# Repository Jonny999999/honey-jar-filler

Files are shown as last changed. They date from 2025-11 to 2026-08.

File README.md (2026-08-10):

# honey-jar-filler

Semi-automatic **weight-based honey jar filler** with a **jar carousel/magazine** and a
**servo-actuated honey gate**. A load cell weighs each jar in real time while the
firmware modulates the gate to hit a target fill mass.

This repository holds the complete build — **KiCad PCB**, **FreeCAD** mechanics, and
**ESP-IDF firmware** — plus the telemetry tooling used to capture and analyse fills.
The machine is also the subject of a **bachelor thesis** that evaluates several
**dosing strategies** for accurately dispensing a viscous, drifting medium (honey);
see [Dosing strategies](#dosing-strategies).

<p align="center">
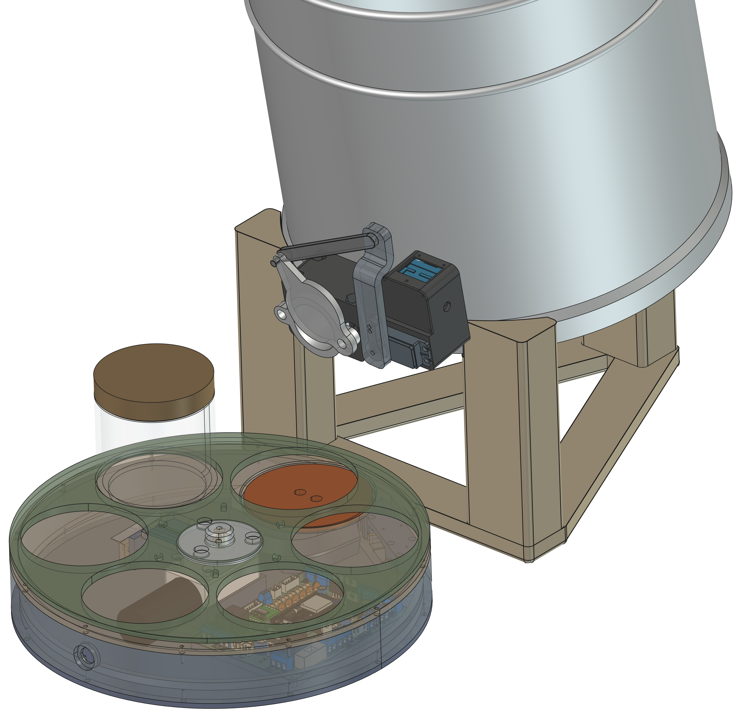
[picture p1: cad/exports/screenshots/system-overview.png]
System overview (CAD)
  
</p>

*System overview (CAD): pressurised bucket on the stand, the servo-actuated gate, and
the carousel base housing the control board and load cell, with a jar in position.*

<p align="center">
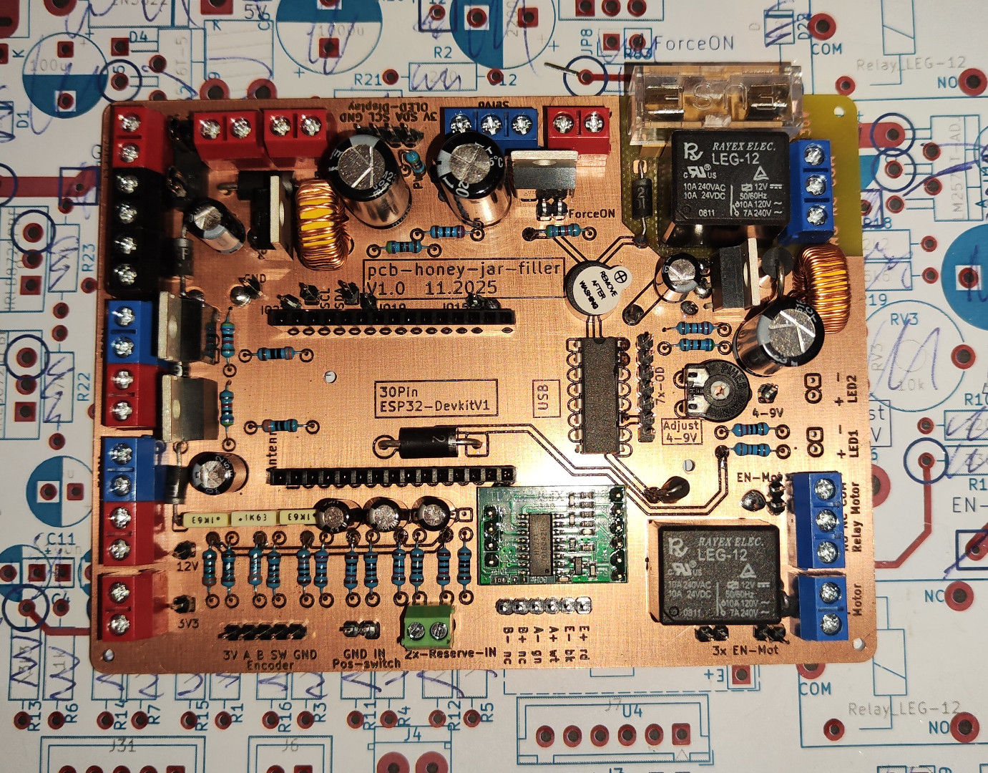
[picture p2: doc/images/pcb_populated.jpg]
Custom board fully populated
  
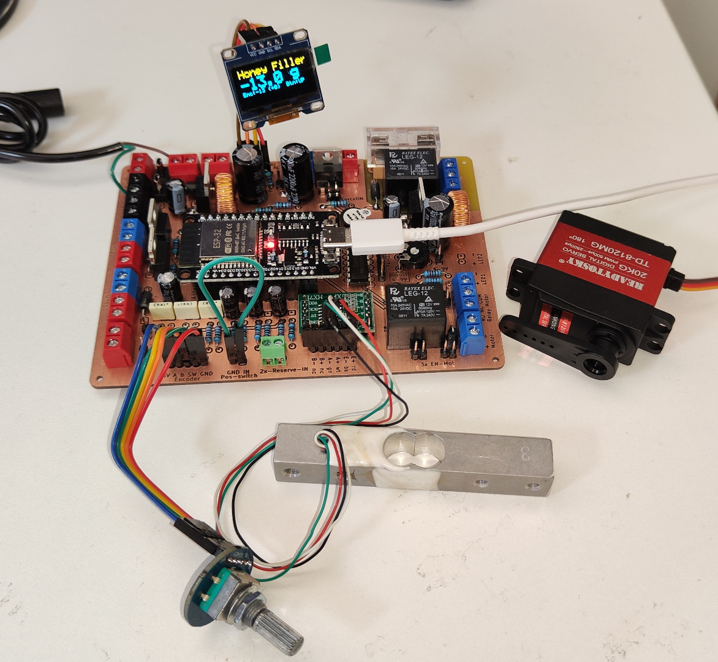
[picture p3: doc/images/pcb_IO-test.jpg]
I/O test with peripherals
  
</p>

*Left: the custom control board, fully populated. Right: I/O bring-up with all
peripherals connected.*

## Repo contents
- `pcb_honey-jar-filler/` — KiCad project (schematic, PCB, exports)
- `cad/` — FreeCAD parts, 3D models, full assembly
- `firmware_honey-jar-filler/` — ESP32 firmware (ESP-IDF)
- `tools/telemetry/` — host-side capture, run-splitting, and plotting tools
- `doc/` — build photos and notes

## Features (PCB / system)
- Load cell input (HX711) for weight-based dosing
- UI: rotary encoder, 2× buttons, LEDs, OLED display (I²C)
- Actuation: servo interface for honey gate; motor output for carousel
- Optional outputs: heater control, tank pressurization valve
- Power: 12–40 V input, 5 V buck (logic), adjustable 4–9 V rail (servo)

## Dosing strategies
Dosing honey accurately is hard: there is a **dead time** of several seconds between
moving the gate and seeing the weight respond, the flow **keeps dripping after the
gate closes**, the gate→flow relationship is **nonlinear**, and disturbances
(viscosity, temperature, falling bucket level) **drift within and between fills**.
Fixed thresholds therefore cannot stay optimal, which is what motivates the strategy
comparison at the heart of the thesis.

The firmware implements the strategies as interchangeable modules
(`firmware_honey-jar-filler/components/filler/`), selectable from the OLED menu:

- **heuristic** — fixed two-stage thresholds; the simple baseline.
- **adaptive-heuristic** — the same fill sequence, but dead time, post-close drip and
  fill rates are learned between fills, so it converges after a jar or two.
- **flow-cascade** — a control-based approach: an outer deceleration rate profile
  (feed-forward trajectory) feeding an inner PI rate loop with an online-identified
  affine plant model and Smith-predictor dead-time compensation.
- **manual** / **sequence** — encoder-driven and scripted modes, used for bring-up and
  for capturing clean reference runs.

## Roadmap / ideas
- Rotary carousel automation (indexing, run/stop with braking)
- Outlet warming (silicone band / water jacket)
- Jar presence detection
- Web UI / profiles / batch counter

## Schematic + layout preview
<p align="center">
  <a href="pcb_honey-jar-filler/export/pcb_honey-jar-filler.pdf">
    Schematic
  </a>
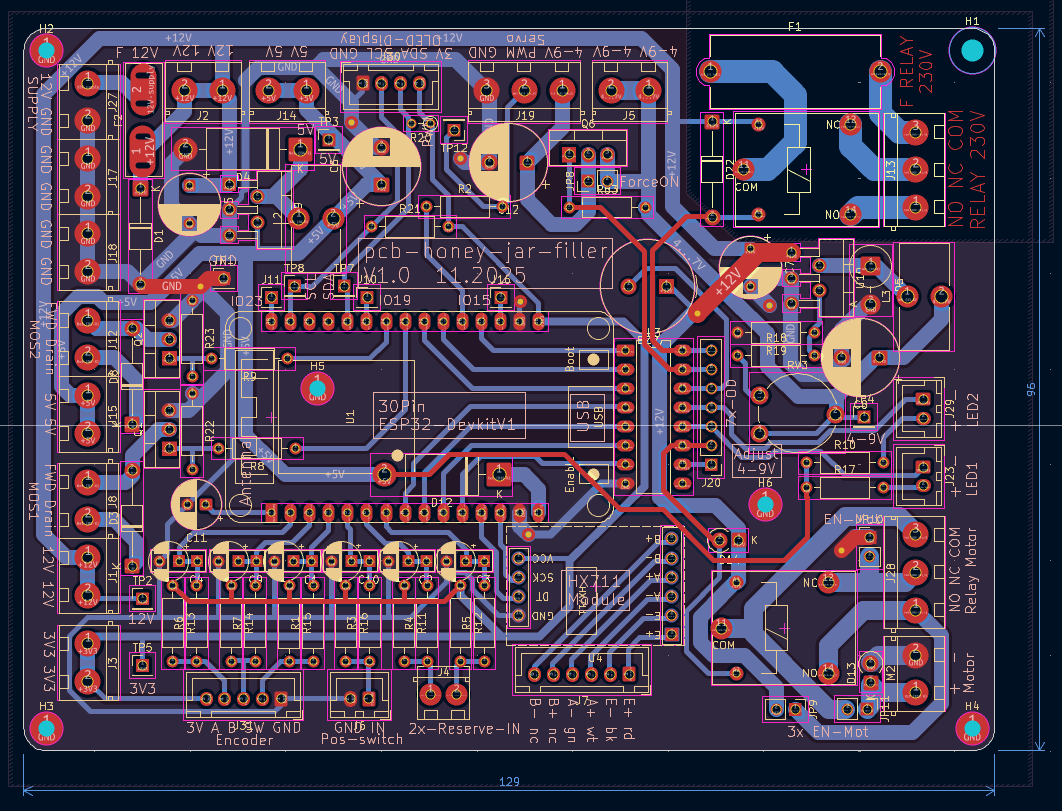
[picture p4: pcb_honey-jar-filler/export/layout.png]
PCB Layout
  
</p>

## Firmware build (ESP-IDF)
- Install ESP-IDF **v5.5.1** and export its environment (`. ./export.sh`).
- Enter the firmware project:
```bash
cd firmware_honey-jar-filler
```
- Set the target and build:
```bash
idf.py set-target esp32
idf.py build
```
- No separate "install components" step is needed — `idf.py build` auto-fetches
  the managed components listed in `main/idf_component.yml` (esp-idf-lib hx711/
  encoder, ssd1306, servo, led_strip) into `managed_components/` on first run.
  `managed_components/` and `build/` are gitignored and regenerated per machine.
- `dependencies.lock` **is** committed and pins exact component versions — do
  not delete it. Some `idf_component.yml` entries use unbounded ranges (e.g.
  `esp-idf-lib/hx711: '*'`), and upstream has shipped breaking API changes
  under those ranges before (`esp-idf-lib/encoder` v2.0.0 rewrote the whole
  API); without the lock file, a fresh clone can silently resolve to an
  incompatible version and fail to compile.
- Flash and monitor (adjust serial port as needed):
```bash
idf.py -p /dev/ttyUSB0 flash monitor
```

## Firmware presets
- Runtime parameters are still defined centrally in `firmware_honey-jar-filler/components/app/app_params_def.h`.
- Each parameter there has one baseline default plus metadata such as min/max/step, UI text, and a scope:
  `APP_PARAM_SCOPE_PRESET` for recipe-specific values and `APP_PARAM_SCOPE_MACHINE` for shared machine settings.
- Built-in preset names and their default overrides live in `firmware_honey-jar-filler/components/app/app.c`.
  These preset defaults only override recipe-scoped fields; they do not duplicate the full parameter list.
- NVS stores shared machine settings separately from editable preset values:
  `machine_v1` for shared settings and `presets_v1` for preset-specific values.
- At boot, the active runtime config is rebuilt from baseline defaults + selected preset defaults + persisted machine settings + persisted preset values.

## Telemetry tools
- Structured telemetry is emitted on the normal UART console with a `TEL ` prefix and JSON payload.
- Normal ESP logs and machine telemetry therefore share one serial stream, but the telemetry lines can be split cleanly on the host.
- The intended workflow is:
  1. capture a session from UART
  2. keep the full console log for debugging
  3. store telemetry separately as NDJSON
  4. split runs and generate thesis figures from those files

Current script layout:
- `tools/telemetry/telemetry_tui.py`
  Recommended interactive wrapper / TUI entrypoint. Guides the user through
  capture, split, and plotting with session discovery, defaults, and command
  previews, while still calling the underlying scripts directly.
- `tools/telemetry/src/`
  Internal shared helpers for the telemetry scripts. Not intended to be run
  directly.
- `tools/telemetry/capture.py`
  Fully usable serial capture tool. Replaces the basic `idf.py monitor` workflow for experiment sessions and shows a live status line with telemetry counters.
- `tools/telemetry/split_runs.py`
  Offline splitter that converts one captured session into per-fill NDJSON files.
  It detects jar filling windows from `state=FILL`, adds configurable pre/post context,
  and writes `fills/index.json` plus `fill_0001.ndjson`, `fill_0002.ndjson`, ...
- `tools/telemetry/plot_runs.py`
  Offline chart exporter for thesis figures. It writes both a plain LaTeX-ready
  chart and a debug variant with metadata, based on fill mass, gate percentage,
  and FSM state overlays.
- `tools/telemetry/strategy_compare.py`
  Cross-strategy comparison charts (accuracy point clouds, speed–accuracy
  trade-off, throughput) for the thesis' strategy-comparison chapter. Reads each
  session's per-fill summaries and is explicit about which runs are a controlled
  comparison and which are only indicative.
- `tools/telemetry/cascade_analyze.py`
  Diagnostics for the flow-cascade strategy: per-fill plant-model estimate
  (gain/onset/lag) beside an offline ground-truth fit, to spot a diverging
  identifier at a glance.

Session capture output:
- `data/telemetry/<session>/session.log`
  Full serial console output, including normal ESP logs and raw `TEL` lines.
- `data/telemetry/<session>/telemetry.ndjson`
  Only telemetry payload lines, one JSON object per line.
- `data/telemetry/<session>/runs/run_0001.ndjson`
  Per-run telemetry files created live from `run_start` / `run_end` events, including configurable pre/post context.
- `data/telemetry/<session>/fills/index.json`
  Offline manifest of detected jar-fill windows with timing, preset, and parameter metadata.
- `data/telemetry/<session>/fills/fill_0001.ndjson`
  One offline per-fill telemetry slice intended for plotting and later comparison.
- `data/telemetry/<session>/session_meta.json`
  Port, baud rate, and capture timing settings.

Example capture usage:
```bash
python3 tools/telemetry/capture.py --port /dev/ttyUSB0 --baud 115200
```

Recommended interactive workflow:
```bash
python3 tools/telemetry/telemetry_tui.py
```

Example offline workflow:
```bash
python3 tools/telemetry/split_runs.py data/telemetry/2026.06.12_11:39-x-test --force
python3 tools/telemetry/plot_runs.py data/telemetry/2026.06.12_11:39-x-test/fills --list
python3 tools/telemetry/plot_runs.py data/telemetry/2026.06.12_11:39-x-test/fills --fills 1,3 --format pdf --format svg
```

Useful options:
- `--show-tel`
  Also print the `TEL` lines in the terminal instead of only saving them to files.
- `--pre-run-ms 2000 --post-run-ms 2000`
  Keep more telemetry context around each detected run.
- `--session-name my-test`
  Add a readable suffix after the timestamp, for example
  `2026.06.07_22:30-x-my-test`.

Goal of this tooling:
- keep experiment data self-describing and reproducible
- avoid manually filtering UART logs after each test
- support later batch plotting to vector PDF/SVG figures for the thesis
- preserve enough event context to compare different presets and control strategies cleanly
- make it obvious during capture that the custom telemetry tool is running, not plain `idf.py monitor`

## Wiring (servo mount DIN cable)
The cable with 15-pin DIN connector from the base assembly to the servo mount carries OLED, encoder, and servo signals + power.

OLED:
- green: GND
- red: 3V3
- orange: SDA
- yellow: SCL

Encoder:
- gray: SW
- blue: B
- light-green: A

Servo:
- brown, gray-brown, pink: 8V
- gray-black, black, white: GND
- purple: PWM

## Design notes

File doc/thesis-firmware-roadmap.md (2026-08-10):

# Thesis Firmware Roadmap

## Purpose

This document captures the current firmware architecture and a practical roadmap for the next three major features:

1. Presets / parameter profiles
2. Web-based configuration and monitoring
3. Detailed process logging for later scientific comparison

The goal is to make future implementation work incremental and reproducible, without having to re-explain the project context.

## Current Firmware Snapshot

The firmware is already structured well enough to extend without a rewrite.

- `firmware_honey-jar-filler/components/app/app.c`
  Stores one versioned `app_params_t` blob in NVS and exposes `app_params_get()` / `app_params_set()`.
- `firmware_honey-jar-filler/components/app/app_params_def.h`
  Central source of truth for parameter defaults, limits, labels, units, descriptions, and grouping.
- `firmware_honey-jar-filler/components/app/app_params_meta.c`
  Builds a metadata table from the parameter definition macros.
- `firmware_honey-jar-filler/components/filler/filler_fsm.c`
  Owns the process state machine and pulls a fresh parameter snapshot every loop.
- `firmware_honey-jar-filler/components/ui/ui_task.c`
  Provides the runtime OLED status screen and direct encoder-based target editing.
- `firmware_honey-jar-filler/components/ui/ui_menu.c`
  Provides a metadata-driven settings menu with explicit save behavior.
- `firmware_honey-jar-filler/main/scale_hx711.c`
  Already has both a polling queue and a thread-safe "latest sample" snapshot.
- `firmware_honey-jar-filler/main/main.c`
  Initializes all peripherals and starts the FSM/UI tasks. There is no networking stack yet.

## Important Observations Before Adding Features

### 1. The current parameter model is centralized

This is a major advantage. Presets and a web UI do not need a second config model if they reuse `app_params_t` plus the existing metadata table.

### 2. Not all parameters should behave like honey presets

Some parameters are "recipe" values, others are "machine calibration" values.

Examples of likely recipe values:

- `target_grams`
- `target_tol_low_g`
- `target_tol_high_g`
- `slow_remaining_g`
- `slow_gate_pct`
- `max_gate_pct`
- `close_remaining_g`
- `drip_delay_ms`
- maybe `empty_glass_min_g` / `empty_glass_max_g` if jar type changes

Examples of machine-level values that should usually not change per honey preset:

- `gate_open_deg`
- `gate_close_deg`
- scale calibration data in `scale_hx711.c`
- maybe `slots_total`

Important detail:

- `gate_open_deg` and `gate_close_deg` are only applied during `gate_init()` in `main/main.c`.
- That means changing them through a preset or web UI will not fully apply live unless gate re-init is added.

Recommendation:

- Keep the first preset implementation simple, but treat calibration values carefully.
- Do not let daily recipe switching accidentally change hardware calibration.

### 3. Current NVS write behavior is fine for OLED use, but not ideal for a web UI

Today, some edits are explicit saves from the menu, but the encoder target adjustment writes to NVS on each change. A web UI with sliders or repeated edits would write far too often.

Recommendation:

- Introduce a RAM working copy plus explicit commit/save semantics before building the web editor.

### 4. The scale update rate is modest

Current default settings are:

- `CONFIG_HX711_POLL_INTERVAL_MS = 280`
- `CONFIG_HX711_AVG_SAMPLE_COUNT = 3`

That is acceptable for slow honey filling and threshold-based control, but may become limiting for more advanced algorithms based on trend or prediction.

Recommendation:

- Keep the current timing initially.
- Re-evaluate sampling rate only after logging exists and actual plots show whether the control signal is too coarse.

## Overall Evaluation

All three ideas are good and realistic.

### Presets

Very realistic and low risk. This is the best next step because it builds directly on the current parameter architecture and immediately helps experimentation.

### Web app

Realistic if kept lightweight. The ESP32 can host a small operator UI in AP mode, but the backend API and config semantics should be stabilized first. A minimal static app plus JSON API is a good fit.

### Logging

Essential for the thesis. This is not optional if the goal is scientific comparison. It is realistic, but it should be implemented as a dedicated telemetry/logging layer rather than scattered `ESP_LOGI()` calls.

## Recommended Order

1. Implement presets and improve parameter persistence semantics.
2. Implement a dedicated telemetry/logging backbone.
3. Add Wi-Fi AP + HTTP API.
4. Build the web UI on top of the API and telemetry stream.
5. Only then start comparing alternative control algorithms.

Why this order:

- Presets solve the immediate operational need.
- Logging should exist before algorithm experiments.
- The web app depends on stable preset/config and telemetry backends.

## Cross-Cutting Design Rule

Add new features through dedicated modules/tasks, not by spreading logic across UI and FSM code.

Recommended new modules:

- `components/presets/`
- `components/telemetry/`
- `components/web/`

The filler FSM should remain responsible for process control, not for storage, HTTP handling, or log transport.

## Task 1: Presets / Parameter Profiles

## Goal

Allow storing multiple named parameter sets and switching between them safely, for example:

- `Summer thin honey`
- `Cold thick honey`
- `500 g jar`
- `Archive 2026-04-22 trial B`

This is useful both operationally and scientifically.

## Why it is a good idea

- It removes the need to remember "good" values manually.
- It supports repeatable experiments.
- It creates a natural unit for later logging: every run can reference a preset name/id/revision.

## Refined decision: split preset settings from machine settings

Yes, the cleaner design is to exclude machine calibration and machine-specific operating limits from per-honey presets.

Recommended split:

- `Preset / recipe settings`
  Values that depend on honey, jar target, or fill strategy
- `Global / machine settings`
  Values that describe the specific hardware or installation

Recommended `global / machine settings` examples:

- `empty_glass_min_g`
- `empty_glass_max_g`
- `advance_timeout_ms`
- `find_ignore_ms`
- `slot_settle_ms`
- `slots_total`
- `gate_open_deg`
- `gate_close_deg`
- `scale_cal_ref_g`

Recommended `preset / recipe settings` examples:

- `target_grams`
- `target_tol_low_g`
- `target_tol_high_g`
- `fill_timeout_ms`
- `slow_remaining_g`
- `slow_gate_pct`
- `max_gate_pct`
- `close_remaining_g`
- `drip_delay_ms`

Why this split is better:

- changing honey should not accidentally change servo calibration
- the same machine can try many honey recipes safely
- logging becomes more meaningful because each run can reference both a `machine config revision` and a `recipe preset revision`
- the web UI becomes easier to understand because the user sees two clear categories

Recommended runtime model:

- keep one unified runtime `app_params_t`
- mark each field as either `PRESET` or `MACHINE`
- at boot, construct runtime params by merging:
  1. firmware base defaults
  2. selected built-in preset defaults
  3. persisted machine settings from NVS
  4. persisted user preset settings from NVS

This keeps the current control code simple because the FSM still reads one parameter struct.

## Recommended implementation

### Phase 1 design

Keep `app_params_t` as the active runtime parameter structure, but add:

- one machine-settings store
- one preset store
- a merge step into the active runtime struct

Suggested data model:

```c
typedef struct {
    char     name[24];
    uint32_t revision;
    int64_t  created_us;
    int64_t  updated_us;
    app_params_t params;
} app_preset_t;

typedef struct {
    uint16_t version;
    uint8_t  active_index;
    uint8_t  preset_count;
    app_preset_t presets[8];
} app_preset_store_t;
```

Suggested NVS layout:

- Namespace: `app`
- Key for machine settings: `machine_v1`
- Key for preset store: `presets_v1`
- Optional key for active working state later: `working_v1`

Suggested machine-settings model:

```c
typedef struct {
    uint16_t version;
    uint32_t revision;
    app_params_t params;
} app_machine_store_t;
```

Important detail:

- only the `MACHINE`-scoped fields inside `params` are meaningful for `machine_v1`
- only the `PRESET`-scoped fields inside `params` are meaningful for each preset

That means the same `app_params_t` and the same metadata can still be reused without duplicate struct definitions.

### Phase 1 API

Create a preset service instead of touching NVS directly from UI or web code.

Suggested API:

```c
void      app_presets_init(void);
esp_err_t app_presets_list(app_preset_t *out, size_t max_items, size_t *out_count);
esp_err_t app_presets_get_active(app_preset_t *out, uint8_t *out_index);
esp_err_t app_presets_select(uint8_t index, bool persist_now);
esp_err_t app_presets_save_active_to_slot(uint8_t index);
esp_err_t app_presets_create_from_active(const char *name, uint8_t *out_index);
esp_err_t app_presets_rename(uint8_t index, const char *name);
esp_err_t app_presets_delete(uint8_t index);
```

Suggested machine-settings API:

```c
void      app_machine_settings_init(void);
esp_err_t app_machine_settings_get(app_params_t *out_machine_only);
esp_err_t app_machine_settings_set(const app_params_t *in_machine_only);
```

### Parameter persistence change

Before presets or web editing, refactor `app_params` into:

- `app_params_get()` to read the current RAM copy
- `app_params_set_ram()` or equivalent public API for immediate runtime updates
- `app_params_commit()` to persist the active working copy to NVS

Reason:

- Web edits should not commit to flash on every input event.
- Preset editing should feel transactional: edit, test, save intentionally.

Recommended future semantics:

- runtime changes can happen immediately in RAM
- explicit save commits only the relevant scope:
  - save preset -> persist only `PRESET` fields into the active preset
  - save machine settings -> persist only `MACHINE` fields into `machine_v1`

### Safety rules

- Preset switching allowed only in `FILLER_IDLE` or `FILLER_FAULT`
- Never switch preset mid-fill
- Show the active preset name on OLED and later on the web UI
- Add a dirty flag when current RAM settings differ from the saved preset

### Migration path from the current firmware

On first boot with preset support:

1. Read the old single `app_params_t` blob if present.
2. Create a default preset from it, for example `Migrated default`.
3. Split the migrated values by scope:
   - `MACHINE` fields go to `machine_v1`
   - `PRESET` fields go to the new default preset
4. Mark that preset active.
5. Save the new store formats.

## OLED / menu behavior before the web app

The OLED should stay useful, but it should not become a full preset editor.

### Main screen

Recommended change:

- always show the active preset name on the normal runtime screen

Because the display is small, use one of these approaches:

- line 3 shows `Preset:<name>` and alternates every 1-2 s with `Btn:START Tgt:150g`
- or line 2 shows compact state info and line 3 always shows preset name

If the name is too long:

- store both a long name and a short label, or
- truncate to fit, for example 12-16 characters

This is worth doing early because it removes ambiguity during testing.

### Menu behavior

Recommended top-level menu flow before the web UI exists:

1. `Preset`
2. `Save to preset`
3. `Machine settings`
4. `Recipe settings`
5. existing actions like tare/calibrate

Minimal first OLED preset behavior:

- selecting `Preset` opens a list of existing presets
- rotating scrolls presets
- clicking applies the selected preset immediately
- application is only allowed in `IDLE` or `FAULT`
- after applying, all recipe-scoped runtime values update together
- machine-scoped values stay unchanged

Recommended save behavior:

- `Save to preset` writes the current recipe-scoped runtime values back to the active preset
- machine settings are not touched

This means the expected operator flow is:

1. choose preset first
2. all recipe values adjust together
3. optionally fine-tune a few recipe settings
4. save back to the active preset if the new tuning is good

That is the simplest usable pre-web workflow.

### Recommended UI scope for the first implementation

OLED support should stay minimal:

- Show active preset name
- Allow preset selection
- Allow "save current recipe to active preset"
- Keep advanced actions like rename/create/delete for the web UI

Do not try to build full preset management on the OLED first. That becomes tedious quickly. Advanced management belongs in the web UI.

### Calibration policy

Recommended policy for phase 1:

- Allow storing all values in the preset payload for simplicity
- But treat machine-calibration fields as advanced settings
- Document clearly that gate calibration may require restart to apply

Optional future refinement:

- Split settings into `machine_config` and `fill_recipe`
- Then presets contain only `fill_recipe`

With your current requirements, this is no longer just optional refinement. It is the recommended direction.

## Built-in preset defaults in the repo

You want named default presets to stay documented in the repo, while NVS overrides them at runtime if the user has saved values. That is a good idea.

Recommended approach:

### Keep one central parameter definition file

Continue using `app_params_def.h` as the single source of truth for:

- field list
- default baseline values
- type
- min/max/step
- labels and descriptions
- new field scope: `PRESET` or `MACHINE`

Do not duplicate full parameter structs per preset in code.

### Add built-in preset definitions as override tables

Recommended pattern:

1. Start from the normal firmware defaults
2. Apply only the preset-specific overrides

Conceptually:

```c
typedef struct {
    const char *name;
    void (*apply_overrides)(app_params_t *p);
} builtin_preset_def_t;
```

Example:

```c
static void preset_thick_honey(app_params_t *p)
{
    p->slow_remaining_g = 80;
    p->close_remaining_g = 180;
    p->drip_delay_ms = 14000;
}
```

Load flow:

1. call `app_params_apply_defaults()`
2. apply built-in preset overrides
3. apply persisted NVS values for that preset if present

Why this avoids chaos:

- adding a new parameter only requires updating the central macro file once
- existing built-in presets automatically inherit the new default unless they specifically override it
- no huge duplicate preset structs need maintenance

### Even cleaner future variant

If you want less handwritten override code later, add a tiny typed override table based on field metadata/offsets. Then a preset can be expressed as "only these fields differ". That keeps built-in presets compact even when many exist.

For the first implementation, simple override functions are sufficient and much easier to debug.

## Implementation steps

1. Add field-scope metadata: `PRESET` vs `MACHINE`.
2. Refactor `app_params` to support RAM-only update, explicit commit, and scope-based copy/merge helpers.
3. Add machine settings store (`machine_v1`).
4. Add preset store (`presets_v1`).
5. Add migration from the current single `params_v1` blob.
6. Add active preset tracking and preset selection API.
7. Expose active preset name/index to UI.
8. Add basic OLED preset selection and save flow.
9. Later expose the same API through HTTP.

## Acceptance criteria

- Multiple named presets can be created, selected, renamed, and deleted.
- Active preset survives reboot.
- Switching presets updates the runtime configuration without corrupting NVS.
- Preset switching is blocked while filling.
- Current preset information is visible locally.

## Risks / caveats

- NVS wear if edits still commit too often
- Confusion if calibration and recipe values are mixed without good naming
- Gate calibration values still being restart-sensitive

## Task 2: Web App for Configuration and Monitoring

## Goal

Provide an easier operator interface than the OLED/encoder for:

- monitoring state live
- viewing current weight and process state
- selecting or editing presets
- changing settings
- later seeing live plots and logs

## Why it is a good idea

- The OLED is good for local fallback, but not for managing many parameters and presets.
- A web UI naturally complements presets and logging.
- It can become the main thesis demo interface.

## Realism

This is realistic on ESP32 if the design stays small and deliberate.

Recommended scope:

- ESP32 in SoftAP mode
- lightweight static frontend
- JSON API for commands and configuration
- SSE for live monitoring stream

Avoid for the first version:

- heavy frontend frameworks unless already justified
- complex authentication systems
- trying to do full database-style storage on the ESP32

## Recommended backend architecture

### Network mode

Start with:

- ESP32 SoftAP mode
- fixed local IP, for example `192.168.4.1`
- WPA2 password configured in code or NVS

Later optional extension:

- AP+STA mode if you want laptop access through existing lab Wi-Fi

### HTTP server

Use ESP-IDF `esp_http_server`.

Recommended endpoints:

- `GET /api/status`
  Returns current machine snapshot
- `POST /api/control/start`
- `POST /api/control/abort`
- `GET /api/params/meta`
  Returns the existing parameter metadata table
- `GET /api/params/current`
- `PUT /api/params/current`
  Updates current working copy only
- `POST /api/params/commit`
  Explicit save
- `GET /api/presets`
- `POST /api/presets`
- `PUT /api/presets/{id}`
- `DELETE /api/presets/{id}`
- `POST /api/presets/{id}/activate`
- `GET /api/stream`
  Server-Sent Events for live data and events

### Why SSE is a good first choice

Use Server-Sent Events before WebSocket.

Reasons:

- simpler implementation
- good fit for one-way live telemetry
- browser support is straightforward
- commands can still use normal REST endpoints

WebSocket is only necessary if SSE becomes limiting later.

### Threading rule

HTTP handlers must not block the FSM or scale task.

Recommended pattern:

- read snapshots from dedicated service functions
- write control requests into queues/flags
- keep web task priority lower than scale/FSM tasks

## Recommended frontend architecture

The frontend should be intentionally small.

Recommended structure:

- single page
- plain HTML/CSS/JS or a very small build setup
- build once, serve static assets from flash

Suggested UI sections:

- machine overview
- current state, fault, slot, active preset
- large live weight readout
- preset selector and preset management
- parameter editor generated from metadata
- start/abort controls
- live plot area
- log export area

### Strong recommendation: metadata-driven parameter forms

Do not hardcode every setting twice.

Reuse:

- labels
- units
- min/max/step
- group names
- descriptions

from the existing parameter metadata. That keeps OLED, firmware, and web UI aligned.

## Suggested machine status payload

Expose a compact snapshot structure like:

```json
{
  "ts_us": 0,
  "state": "FILL",
  "fault": "NONE",
  "slot_index": 2,
  "slots_total": 6,
  "active_preset": "Cold thick honey",
  "weight_g": 132.4,
  "raw_weight": 123456,
  "jar_tare_g": 84.1,
  "relative_fill_g": 48.3,
  "gate_pct": 20,
  "motor_on": false,
  "params_dirty": false
}
```

This same snapshot can later feed the web monitor and telemetry logger.

## Implementation steps

1. Add Wi-Fi AP startup module.
2. Add HTTP server with a minimal `/api/status`.
3. Expose parameter metadata and current parameters.
4. Expose preset APIs.
5. Add SSE stream for status updates and events.
6. Add a minimal static frontend.
7. Add live plots after telemetry backend exists.

## Acceptance criteria

- A laptop/phone can connect directly to the ESP32 AP.
- The browser shows live machine status without serial monitor.
- Parameters can be edited and explicitly saved.
- Presets can be managed from the browser.
- Local OLED control still works as a fallback.

## Risks / caveats

- Flash/RAM limits if the frontend becomes too heavy
- Network handlers accidentally coupling too tightly to control logic
- Frequent browser edits causing too many flash writes if commit semantics are not fixed first

## Task 3: Detailed Logging for Scientific Comparison

## Goal

Create a reliable and clean logging system for later thesis analysis, including:

- time series of process values
- state transitions
- faults
- preset and parameter context
- per-run summaries

## Why it is a good idea

This is the most important thesis-oriented feature because it turns "it feels better" into measurable evidence.

Without structured logs, comparing parameter sets or control strategies will be weak.

## Core recommendation

Do not rely on scattered `ESP_LOGI()` output as the scientific log.

Instead, create a dedicated telemetry/logging module with a stable record format and separate output transports.

## Recommended architecture

### Logging layers

1. Producers
   The scale task, filler FSM, UI, preset service, and later web/API layer produce telemetry records.
2. Telemetry queue
   A single queue receives structured records.
3. Telemetry task
   One task timestamps, enriches, buffers, and forwards records.
4. Transports
   UART, Wi-Fi SSE, and optional on-device ring buffer use the same record source.

### Record types

Suggested record classes:

- `RUN_START`
- `RUN_END`
- `STATE_CHANGE`
- `FAULT`
- `SAMPLE`
- `GATE_COMMAND`
- `PARAM_CHANGE`
- `PRESET_CHANGE`
- `USER_ACTION`
- `NOTE`

### Suggested telemetry record

```c
typedef enum {
    TEL_RUN_START,
    TEL_RUN_END,
    TEL_STATE_CHANGE,
    TEL_FAULT,
    TEL_SAMPLE,
    TEL_GATE_COMMAND,
    TEL_PARAM_CHANGE,
    TEL_PRESET_CHANGE,
    TEL_USER_ACTION,
} telemetry_kind_t;

typedef struct {
    int64_t ts_us;
    uint32_t run_id;
    telemetry_kind_t kind;
    filler_state_t state;
    filler_fault_t fault;
    uint8_t slot_idx;
    float weight_g;
    float jar_tare_g;
    float relative_fill_g;
    float gate_pct;
    uint32_t target_g;
    char preset_name[24];
    uint32_t preset_revision;
    uint16_t algorithm_id;
    uint16_t algorithm_revision;
} telemetry_record_t;
```

The exact struct can change, but the design should include:

- timestamp
- run id
- preset identity
- algorithm identity
- main process values

## What should be logged

### Per-sample time series

At each published sample, capture at least:

- timestamp
- raw scale value
- calibrated weight
- relative fill weight
- FSM state
- slot index
- gate command percent
- target grams
- active preset id/name
- run id

### Events

Log immediately:

- start requested
- abort requested
- state changes
- near-close transition
- close-early transition
- refill decision
- overweight fault
- motor timeout
- scale stale fault
- preset switched
- parameters committed

### Per-run summary

At the end of each jar or run, produce a summary containing:

- run id
- preset id/name/revision
- algorithm id/revision
- start/end timestamps
- initial jar tare
- final net fill weight
- absolute error from target
- refill count
- time spent filling
- time spent dripping
- final result: ok / skipped / fault

This summary is extremely useful for thesis tables even without plotting the full time series.

## Transport recommendation: separate data model from transport

### UART

Best for first implementation.

Advantages:

- simple
- reliable
- easy to capture on a laptop
- good for debugging before Wi-Fi exists

Recommended output format:

- NDJSON or CSV lines

NDJSON is especially attractive because the same record format can later be reused over HTTP/SSE.

### Wi-Fi

Best for integration with the web UI once the API exists.

Recommended use:

- live telemetry stream to browser
- optional host-side logger tool over HTTP/SSE

### On-device persistence

Do not try to persist high-rate full time series in NVS.

Reasons:

- too much flash wear
- too little capacity
- unnecessary complexity

Recommended instead:

- keep a RAM ring buffer for recent records
- optionally persist only per-run summaries
- store full data on a connected host via UART or Wi-Fi

## Recommended first implementation strategy

### Phase 1

Add telemetry module and UART export only.

This is enough to:

- collect real experiment data
- inspect plots on a laptop
- validate the record format

### Phase 2

Expose the same telemetry stream via Wi-Fi SSE and show it in the web app.

### Phase 3

Add host-side tooling in the repo, for example:

- `tools/log_capture.py`
- `tools/plot_run.py`
- `tools/notebooks/`

The thesis analysis will almost certainly be easier in Python/pandas/matplotlib than inside the ESP32 itself.

## Clean integration points in the current code

Recommended producers:

- `main/scale_hx711.c`
  Publish `SAMPLE`
- `components/filler/filler_fsm.c`
  Publish state transitions, faults, run start/end, gate decisions
- `components/app/` or future preset service
  Publish param commit and preset change events
- `components/ui/ui_task.c`
  Publish user actions like start/abort or target edits if useful

## Acceptance criteria

- Each experimental run has a unique run id.
- Logs can be captured on a laptop without modifying the control loop.
- Logs include preset identity and enough state to reconstruct the fill process.
- Per-run summaries can be exported for thesis tables.
- Live monitoring later reuses the same telemetry source.

## Risks / caveats

- Logging too much directly from high-priority tasks
- Mixing debug logs with scientific logs
- Depending only on browser-side capture for important data

## Recommendation on Algorithm Experiments

Do not start with multiple new control algorithms before presets and logging exist.

First make experiments repeatable and measurable.

After that, the firmware should expose an explicit algorithm identity, for example:

- `ALGO_THRESHOLD_V1`
- `ALGO_THRESHOLD_V2`
- `ALGO_PREDICTIVE_CLOSE_V1`

Recommended future refactor:

- keep the FSM states
- isolate the fill decision logic behind a controller function or small strategy interface

This will make comparisons much cleaner in the thesis because only the control strategy changes while the surrounding machine logic stays constant.

## Final Recommendation

The three ideas are worthwhile, but they should not be started in parallel.

Best next action:

1. Presets plus better config persistence semantics
2. Structured telemetry/logging
3. Wi-Fi API
4. Web UI

If only one feature is implemented next, it should be presets.

If the goal is specifically thesis quality, the second feature after presets should be logging, not the web UI.

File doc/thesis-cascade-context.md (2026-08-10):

# Thesis context brief — regelungsbasierter Ansatz (flow-cascade)

**Purpose.** Self-contained context for a separate Claude session that writes the
LaTeX thesis section on the cascade / control-based dosing strategy. It captures
the *design rationale, rejected alternatives, and limitations* that are NOT
recoverable from reading the code alone, plus pointers to the code and the
telemetry data to interpret. Read this together with the code and the charts;
this file is the "why", the code is the "what", the telemetry is the "results".

> **Do not paste code verbatim into the thesis.** Use this to reason about and
> justify the design in prose/equations in Jonny's established chapter style.

---

## 0. Target file / chapter — CONFIRM FIRST

Jonny pointed at `09_erweiterte_dosierstrategie.tex`, but the chapter naming says
otherwise. Current chapters in `/home/jonny/HAW-LA/s8/latex/Chapters/`:
- `08_heuristische_dosierstrategie.tex` — heuristic (baseline).
- `09_erweiterte_dosierstrategie.tex` — **adaptive-heuristic** (the "erweiterte"
  learning strategy). The cascade is NOT this one.
- `10_regelungsbasierter_ansatz.tex` — **the cascade / control-based approach.
  This is the section this brief is for.**
- `11_strategievergleich.tex` — comparison.

→ The cascade material almost certainly belongs in **`10_regelungsbasierter_ansatz.tex`**.
Confirm with Jonny before writing into `09`. (09 and 10 share the same learning
substrate, so some cross-referencing between them is expected.)

---

## 1. Absolute paths

**Firmware — the cascade strategy and its shared substrate**
- Cascade implementation (primary):
  `/home/jonny/projects/honey-jar-filler/firmware_honey-jar-filler/components/filler/filler_strategy_flow_cascade.c`
- Runtime/learned-entry structs, telemetry field defs:
  `/home/jonny/projects/honey-jar-filler/firmware_honey-jar-filler/components/filler/filler_strategy.h`
- Adaptive strategy (shared learning model, ch.09, useful for contrast):
  `/home/jonny/projects/honey-jar-filler/firmware_honey-jar-filler/components/filler/filler_strategy_adaptive_heuristic.c`
- Flow-control strategy (single P-loop, the conceptual step *before* the cascade):
  `/home/jonny/projects/honey-jar-filler/firmware_honey-jar-filler/components/filler/filler_strategy_flow_control.c`
- Sequence strategy (scripted plant probe, produces the clean Strecke reference):
  `/home/jonny/projects/honey-jar-filler/firmware_honey-jar-filler/components/filler/filler_strategy_sequence.c`
- Preset params (targets/seeds/bounds): 
  `/home/jonny/projects/honey-jar-filler/firmware_honey-jar-filler/components/app/app_params_def.h`

**Supporting docs**
- Handoff/orientation (project-wide context): `/home/jonny/projects/honey-jar-filler/CLAUDE.md`
- Hardware retest checklist for the cascade fixes:
  `/home/jonny/projects/honey-jar-filler/doc/cascade-affine-gain-testnotes.md`

**Telemetry data — 2026-07-05 hardware session** (dir:
`/home/jonny/projects/honey-jar-filler/data/telemetry/`). Each run dir has
`telemetry.ndjson` (per-sample) + a per-fill summary; plot with
`tools/telemetry/plot_runs.py`.
- `2026.07.05_21:00-x-dunkler-honig_cascade_ratereduced-learnfromoverfill/` —
  **THE cascade run to discuss.** Real dark honey. Shows the three problems the
  fixes address (overfill +15..23 g every fill, gate stays ~full open until
  close, model K drifts 0.59→0.29). This is "cascade, pre-fix" data.
- `2026.07.05_19:55…_cascade-default01/`, `…20:07…cascade-02-fix-more-flow/`,
  `…20:21…cascade-03-allow100percent/`, `…20:24…cascade-04-retry/` — earlier
  same-day cascade runs on **dummy honey** (tuning iterations; lower value,
  context only).
- `2026.07.05_21:09-x-dunkler-honig_sequence_30-70longer/` — **scripted Strecke
  probe** (sequence strategy, gate 30 %→70 %→close). Best data for showing the
  raw plant response in isolation: dead time, rate build-up per gate step,
  post-close drip. Use for the Strecke/Prozessanalyse figure this section leans on.
- `2026.07.05_21:10-x-dunkler-honig-manual-sweep/` — **manual gate sweep**.
  Directly evidences the gate→flow relationship (nonlinearity + non-zero flow
  onset). Strong empirical support for the affine-model justification below.
- `2026.07.05_20:41…adaptive_default-quick-learn/`,
  `…20:45…adaptive_slow-learning/` — adaptive strategy (ch.09 learning trend).
- `2026.07.05_21:13…flowcontrol_rest/` — flow-control strategy.

> Caveat: all cascade fills in these runs are **pre-fix**. The affine-model +
> overfill + profile fixes (commit `63dc0d6`) are **untested on hardware**. Write
> the results section around the pre-fix data as "erste Inbetriebnahme / erkannte
> Probleme", and frame the fixes as the corrective design step — do NOT claim
> post-fix performance numbers until a retest exists.

---

## 2. What the cascade strategy is (architecture)

The "regelungsbasierter Ansatz": a **cascade control** with feedforward and
dead-time compensation, closing the loop on the **mass flow rate** ṁ rather than
on weight thresholds. Actuator is the gate/flap position α ∈ [0,100] %; the
controlled variable inside the loop is ṁ [g/s]; the outer objective is hitting
the target mass.

Layers, outer → inner:

1. **Outer trajectory / deceleration profile** (`profile_target_rate_gps`,
   flow_cascade.c ~L547). A *function of the remaining mass*, NOT a feedback
   loop. Produces the rate setpoint ṁ*(remaining):
   - `terminal = clamp(fast · 0.25, 3 g/s, fast)` — a genuine slow approach rate.
   - `in_flight = L̂·ṁ_meas + post_close_gain` — mass that will still arrive after
     "now" (dead-time + drip), subtracted so the taper is referenced to the
     mass that is *still controllable*: `eff_remaining = remaining − in_flight`.
   - `band = max(20 g, post_close·1.6 + L̂·fast)` — the deceleration window width,
     scaled by the plant's own lag/drip.
   - `frac = clamp(eff_remaining / band, 0, 1)`;  **ṁ\* = terminal + (fast − terminal)·frac**.
   → a linear taper from the fast cruise rate down to the terminal approach rate
   as the jar fills.

2. **Inner PI rate loop with feedforward** (`cascade_control_step`, ~L590):
   - Feedforward (Steuerung baseline): **gate_ff = (ṁ* − b) / K̂** — invert the
     learned affine plant model to get the gate that should produce ṁ*.
   - PI trims the residual: `gate = gate_ff + Kp·e + I`, with `Kp = 1.2 %/(g/s)`,
     integral gain `Ki = 0.40 %/(g/s·s)`, anti-windup clamp `I ∈ ±35 %`,
     per-update slew clamp `±6 %`, deadband `0.6 g/s`.
   - **Dead-time-paced holdoff**: the integrator is advanced by a holdoff time
     tied to the dead time (300–2500 ms), so the loop does not react faster than
     the plant can physically respond — a pragmatic dead-time defense.

3. **Smith predictor** (`cascade_update_model`, ~L389) forms the feedback the PI
   error uses: **e = ṁ* − fb**, where **fb = ŷ + (ṁ_meas − ŷ_d)**.
   - ŷ = model rate: the affine steady-state rate `K̂·gate + b` passed through a
     first-order lag `τ = 0.60 s` (`CASC_MODEL_TAU_S`).
   - ŷ_d = ŷ delayed by the learned dead time L̂ (a 256-deep ring buffer).
   - Cold-start: while history < L̂, ŷ_d = 0, which prevents predictor windup
     during the initial dead time when measured rate is also ~0.
   → Standard Smith structure: the controller "sees" the fast model prediction ŷ
   for responsiveness, corrected by the slow real measurement mismatch
   (ṁ_meas − ŷ_d) for accuracy.

4. **Online plant identification** — the affine model `K̂, b` (section 3).

**Shared FSM & learning substrate** (common with adaptive/flow-control):
`FILLER_FILL → DRIP_WAIT → VERIFY_TARGET → (refill loop)`. Per-preset learned
entries via count-warmup EWMA (`learn_ewma`, `α = max(base, 1/(n+1))`) so the
first successful fill dominates the conservative seed → converges in ~1–2 jars.
Learned per preset: dead_time, post_close_gain, fast/slow rate, drip_wait,
finish_trim, and `K̂,b`. **Learned state is RAM-only** (no NVS) — a reboot resets
to seeds; this is intentional so cold-start convergence is demonstrable.

---

## 3. The central design decision: the plant model  ṁ = K̂·gate + b

This is the most defensible/interesting design story for the thesis, because two
alternatives were tried and rejected first.

**The plant:** gate→flow is nonlinear, has a **non-zero flow onset** (~15 % gate
before any honey moves — see the manual-sweep run), and drifts with viscosity /
temperature / falling bucket level. So no fixed gate↔rate map holds.

**Attempt 1 — single scalar gain K̂ (`ṁ = K̂·gate`, line through origin).**
Failed because forcing the line through the origin makes `K̂ = ṁ/gate`
operating-point-dependent: near onset it's small, wide open it's larger. Sampling
K̂ at 60 % gate then using it at 30 % mis-predicts. In the 07-05 cascade run this
showed as an *apparent* K drift 0.59→0.29 — not the plant changing, but the
scalar being read off a curve at different points.

**Attempt 2 — 6-point gate→rate breakpoint schedule (10/20/…/90 %), interpolated.**
Rejected on a structural argument (this is the key insight): **the cascade
controller only ever visits two gate regimes** — a high gate during the fast
cruise phase and a low gate during the terminal approach. It never parks at the
intermediate breakpoints long enough (past the dead time) to gather steady-state
data there, so those points stay at their seed values forever and the
interpolation is fiction. A model the controller cannot excite is untrainable.

**Chosen — affine model `ṁ = K̂·gate + b`.** One slope + one offset:
- `b` (offset, clamped [−60, +15] g/s, **normally negative**) captures the flow
  onset the origin-line missed. Interpretation: gate at which flow starts ≈ −b/K̂.
- Fit **live from exactly the two operating points the controller does visit**:
  the fast phase feeds a high-gate EWMA point (gate_hi, rate_hi), the slow phase
  a low-gate point (gate_lo, rate_lo). Refit each update: `K̂ = Δrate/Δgate`,
  `b = rate_hi − K̂·gate_hi`, but only when the two gates are ≥ 8 %
  (`CASC_GAIN_MIN_GATE_SEP_PCT`) apart (else hold K̂, re-solve only b).
- Samples are taken **only in steady state** — gate held longer than
  `L̂ + 0.5 s` — so a measured rate reflects the *current* gate, not the one
  commanded a dead time ago. In-fill EWMA `α = 0.15`; the converged K̂,b persist
  across fills via signed-safe `learn_ewma`.
- **First-fill caveat:** `b` seeds to 0, so the very first fill's feedforward runs
  slightly rich at low gates until `b` is learned. Converges within a fill or two.

Framing for the thesis: this is a **linearized (affine) secant model** valid
*between* the two operating points, identified online — deliberately the simplest
model that (a) the controller can actually excite and (b) captures the onset
offset. Honest about being a local approximation of a nonlinear Strecke.

---

## 4. Steuerung vs. Regelung — the terminology framing

Useful for precise German control-engineering language:
- The **outer deceleration profile is a Steuerung / Trajektoriengenerator**: ṁ*
  is a pure function of remaining mass, no feedback. It is *not* a control loop.
- The **inner PI + feedforward is the Regelung**: feedback closes on the rate
  error via the Smith-predicted rate.
- The **feedforward term (gate_ff = (ṁ*−b)/K̂) is a modellbasierte Vorsteuerung**
  inside the Regelung — it does the bulk of the work; the PI only trims.
- The overall structure = **Kaskadenregelung mit Smith-Prädiktor und Vorsteuerung**.
Calling the whole strategy "regelungsbasierter Ansatz" is correct; be precise
that the outer layer itself is a Steuerung.

---

## 5. Why a smooth taper instead of a hard step (design justification)

For a plant with **dead time + drip (Nachlauf)**, arriving at the close point
*slowly* is what makes the close precise. Reasons to develop in prose:
- **Dead time:** a command arrives ~L̂ later. A hard step down still has the old
  high flow in flight during L̂ → overshoot. A ramp bleeds the rate down *before*
  the close, so the in-flight mass in the final L̂ is already small.
- **Drip ∝ rate-at-close:** post-close gain scales with the flow when the gate
  shuts. Arriving at ~terminal (≈0.25·fast) instead of full rate makes the drip
  small *and predictable*, which is what the post-close-gain learning relies on.
- **Loop health:** a hard step slams the PI with a huge transient and excites
  windup; the ramp keeps the error small and the loop in its linear regime.
- The optimum is "arrive as slowly as precision needs, but no slower" (slower =
  wasted cycle time). Linear taper = simplest monotonic profile with an
  independently tunable terminal rate. A `sqrt`/constant-deceleration profile
  would be marginally more time-optimal — note as *Ausblick/future work*, not done.

---

## 6. Deliberately NOT implemented (limitations / future work — be honest)

Good thesis material; frame as documented limitations, several absorbed to first
order by other mechanisms:
- **Within-fill dead-time variation not compensated.** L̂ is measured once at fill
  start and held constant, but L actually *shrinks* as the jar fills (fall height
  drops). The `finish_trim` cross-run integrator + the Smith correction absorb the
  resulting bias to first order, but it is not explicitly modeled.
- **K̂ is a single linearized/affine secant**, sampled only in steady state.
  Gate→flow is genuinely nonlinear; extrapolating K̂,b outside the two operating
  points is unreliable.
- **No NVS persistence** of learned state — reset on reboot (intentional for the
  cold-start demonstration, but a product would persist it).
- **Terminal rate is a fixed fraction (0.25) of fast**, not itself optimized.
- **Two-point ID needs a distinct slow phase** (≥ 8 % gate separation). If a fill
  never really slows, only `b` updates and K̂ is held — a structural dependency
  worth stating.
- **Untested post-fix on hardware** — the affine model and the overfill/profile
  fixes are validated only in reasoning/replay, not yet on the machine.

---

## 7. The empirical story (interpreting the 07-05 cascade run)

The `…21:00…cascade_ratereduced-learnfromoverfill` run is the honest "erste
Inbetriebnahme" evidence. Three coupled failure modes, all with a root cause:
1. **Overfill +15..23 g every fill.** Root cause: the close-threshold clamp
   collapsed to 10 g while the predicted remaining-at-close was 70+ g, so the
   gate closed far too late. (Also a double-count: post_close_gain already
   includes the in-flight mass, and the old code added dead_time·rate on top.)
2. **Gate stayed ~fully open until the very end** (no visible deceleration).
   Root cause: fast_rate and slow_rate had both collapsed to ~30 g/s, so the
   taper referenced to the learned slow rate was flat.
3. **Model prediction drifted worse across fills** — the scalar-K artifact of
   section 3 (K read off a nonlinear curve at a shifting operating point).

The corrective design step (commit `63dc0d6`): affine model (fixes 3), decouple
terminal rate from the learned slow rate as `0.25·fast` (fixes 2), and fix the
close-threshold clamp + remove the double-count (fixes 1). Present the fixes as
*design iterations driven by the measured Strecke behaviour* — a strong narrative
for a "regelungsbasierter Ansatz" chapter.

Supporting figures worth generating: the **manual-sweep** run for the gate→flow
nonlinearity + onset (justifies the affine model empirically); the **sequence**
run for the isolated Strecke response (dead time, per-step rate build-up, drip);
the cascade run for the failure modes above.

---

## 8. Key constants (values, for the equations/tables)

From `filler_strategy_flow_cascade.c`. Cite as tuned #defines, not learned.

| Constant | Value | Meaning |
|---|---|---|
| `CASC_KP_PCT_PER_GPS` | 1.2 | PI proportional gain [%/(g/s)] |
| `CASC_KI_PCT_PER_GPS_S` | 0.40 | PI integral gain [%/(g/s·s)] |
| `CASC_STEP_MAX_PCT` | 6.0 | max gate change per update [%] |
| `CASC_INTEG_LIMIT_PCT` | ±35 | anti-windup integrator clamp [%] |
| `CASC_DEADBAND_GPS` | 0.6 | rate-error deadband [g/s] |
| `CASC_HOLDOFF_MIN/MAX_MS` | 300 / 2500 | dead-time-paced integrator holdoff [ms] |
| `CASC_TERMINAL_RATE_FRAC` | 0.25 | terminal rate = frac·fast |
| `CASC_RATE_MIN_FLOOR_GPS` | 3.0 | terminal-rate floor [g/s] |
| `CASC_DECEL_BAND_MIN_G` | 20 | min deceleration window [g] |
| `CASC_DECEL_BAND_MULT` | 1.6 | post_close multiplier in band width |
| `CASC_GATE_GAIN_MIN/MAX` | 0.02 / 3.00 | affine slope K̂ bounds [g/s per %] |
| `CASC_GAIN_B_MIN/MAX` | −60 / +15 | affine offset b bounds [g/s] |
| `CASC_GAIN_MIN_GATE_SEP_PCT` | 8 | min gate separation to refit slope [%] |
| `CASC_GAIN_SETTLE_MARGIN_S` | 0.5 | settle margin over L̂ before sampling [s] |
| `CASC_GAIN_LIVE_ALPHA` | 0.15 | in-fill operating-point EWMA α |
| `CASC_MODEL_TAU_S` | 0.60 | Smith model first-order lag τ [s] |
| `SMITH_DELAY_MAX` | 256 | Smith delay ring-buffer depth |

Telemetry fields to reference in result plots (per-sample NDJSON): `weight`,
`gate`, `filtered_rate`, `target_rate_gps` (ṁ*), `rate_error_gps`,
`model_rate_gps` (ŷ), `model_delayed_gps` (ŷ_d), `control_integ_pct` (PI state),
`gate_gain_gps_per_pct` (K̂). Per-fill summary has `used_*`/`next_*` for
learning-trend plots.

---

## 9. Suggested section structure (10_regelungsbasierter_ansatz.tex)

1. Motivation: why thresholds/heuristics can't stay optimal on a drifting,
   dead-time+drip plant → close the loop on rate (link back to ch.07 Strecke).
2. Regelungskonzept: the cascade (Steuerung profile → PI+Vorsteuerung → Smith),
   with the block diagram (drawio `diagrams_flow-cascade_DRAFT.drawio`).
3. Streckenmodell: the affine ṁ = K̂·gate + b, the online two-point ID, and the
   rejected-alternatives argument (scalar / breakpoints) — the design highlight.
4. Trajektorie/Steuerung: the deceleration profile + why smooth vs. hard step.
5. Totzeitkompensation: the Smith predictor.
6. Inbetriebnahme & erkannte Probleme: the 07-05 results + corrective iteration.
7. Grenzen & Ausblick: section 6 limitations.

Keep consistent with ch.08/09 style (pastel figures, `#555555` borders,
Helvetica 13 in diagrams). Cross-reference the shared learning model in ch.09
rather than repeating it.

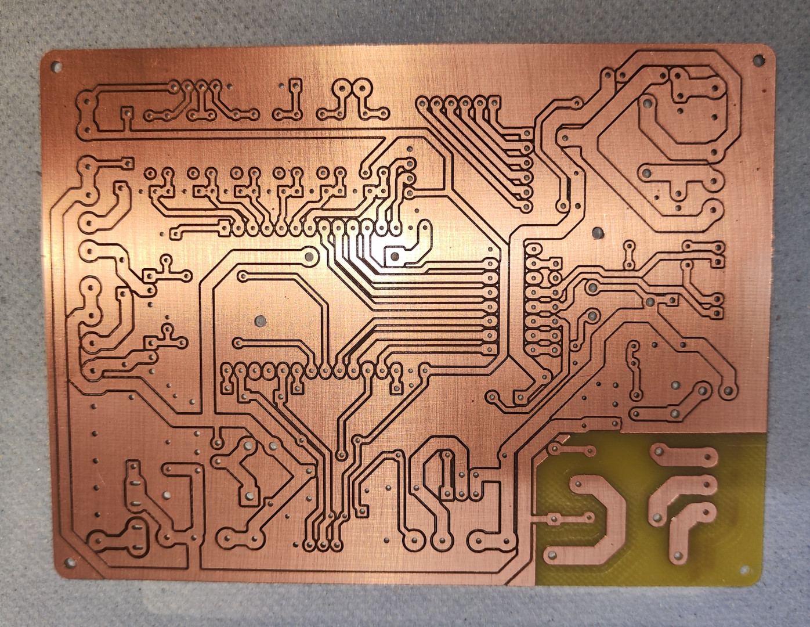
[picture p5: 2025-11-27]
doc/images/pcb_milled.jpg

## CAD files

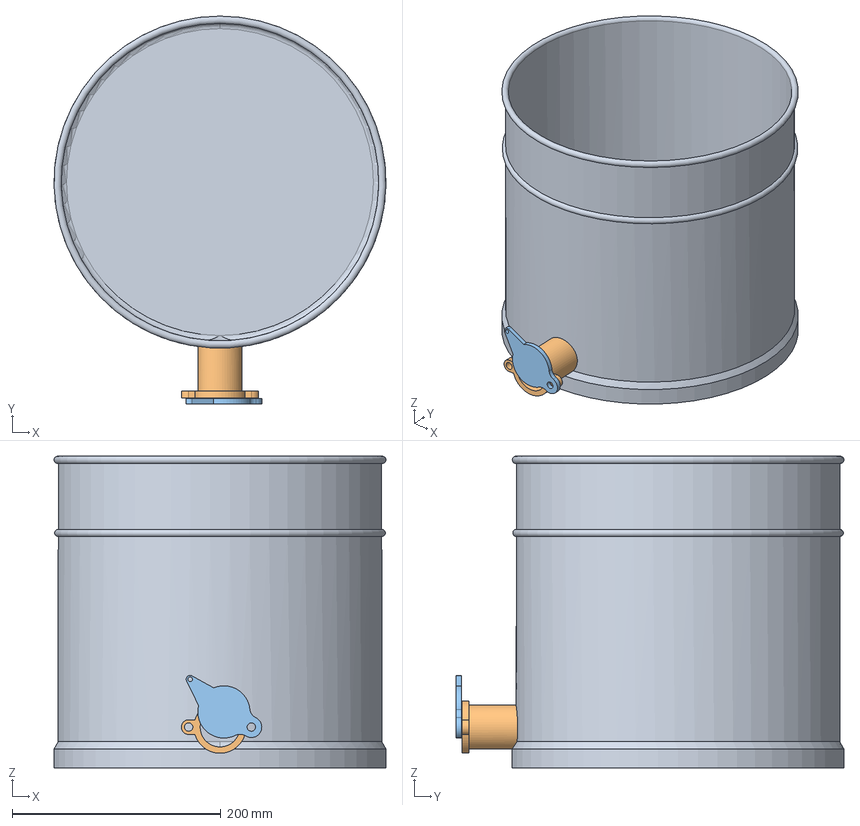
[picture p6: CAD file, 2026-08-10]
cad/parts/bucket.FCStd
318.0 x 371.5 x 298.5 mm
bucket_base
discharge
lid

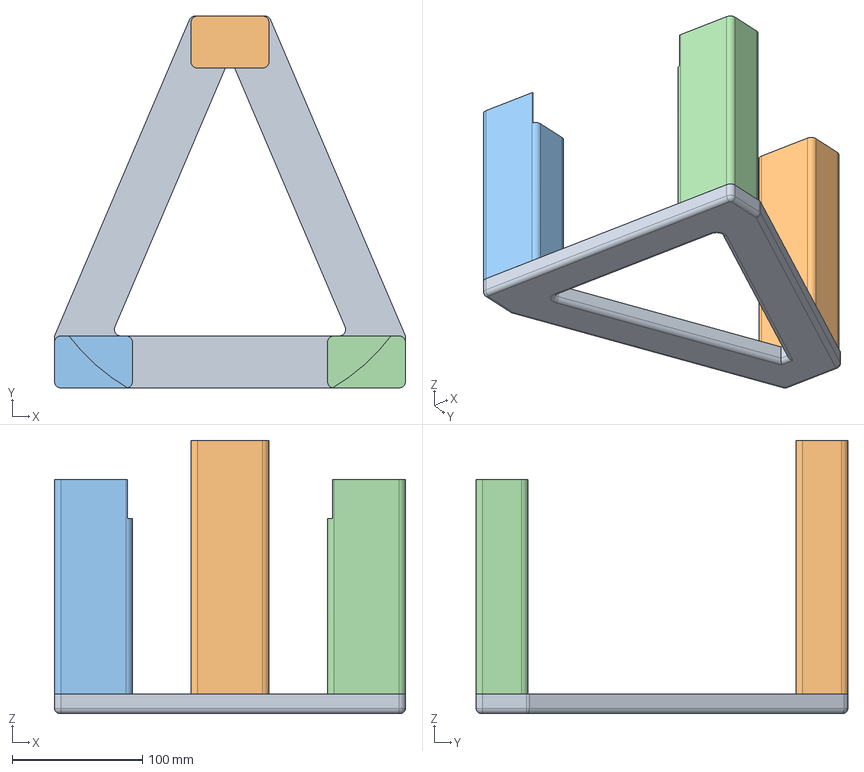
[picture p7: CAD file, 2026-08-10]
cad/parts/bucket-stand.FCStd
270.0 x 286.1 x 210.0 mm
base
rear-piece
front-piece
front-piece (Mirror #1)

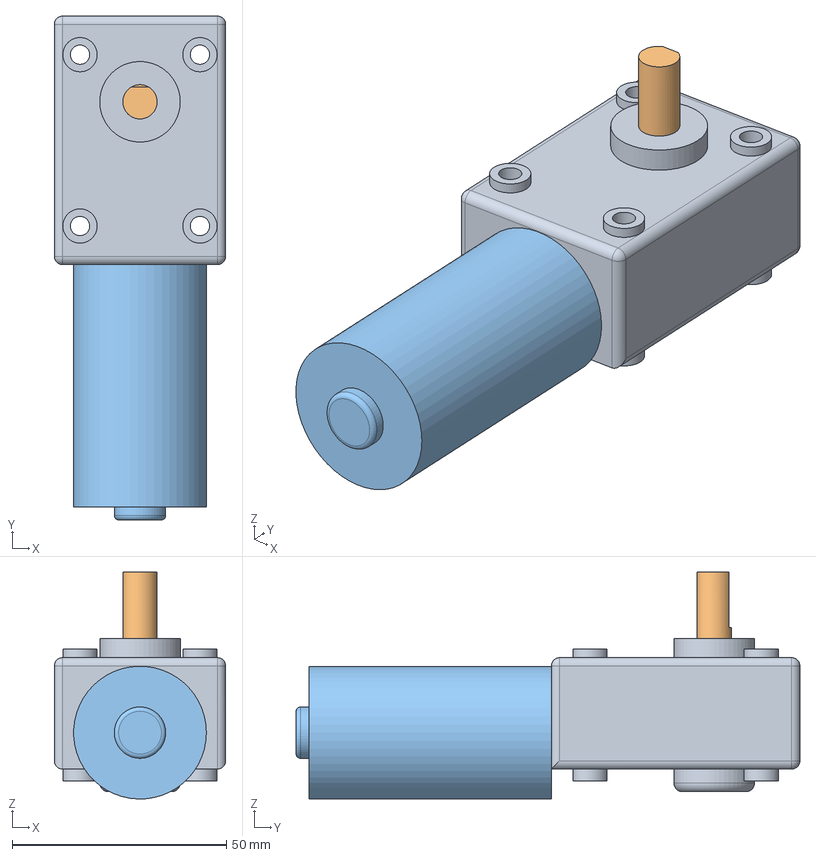
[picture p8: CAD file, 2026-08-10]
cad/parts/gearboxed-motor.FCStd
40.0 x 117.6 x 53.0 mm
gearbox
shaft
motor

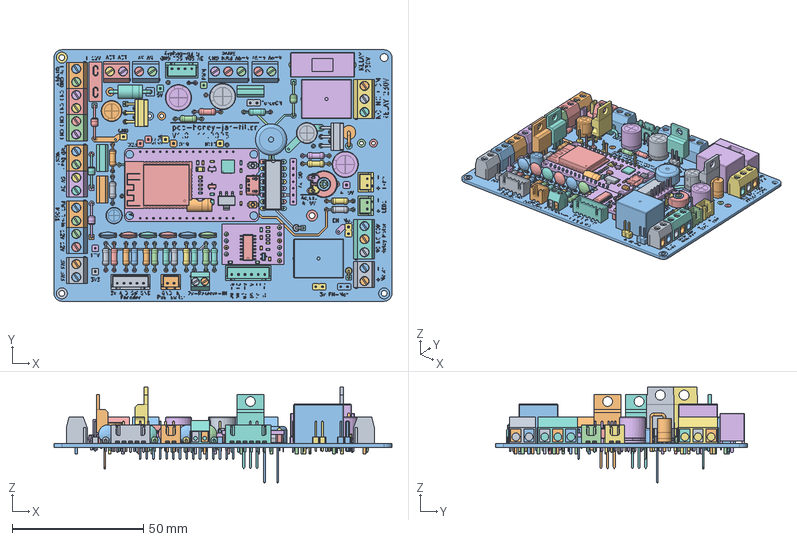
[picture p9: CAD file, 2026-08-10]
cad/parts/pcb.FCStd
129.0 x 96.0 x 36.4 mm
JST_XH_B5B-XH-A_1x05_P2.50mm_Vertical
R_Axial_DIN0207_L6.3mm_D2.5mm_P10.16mm_Horizontal
C_Disc_D7.0mm_W2.5mm_P5.00mm
D_T-1_P12.70mm_Horizontal
terminal-case
terminal
terminal001
C_Disc_D7.0mm_W2.5mm_P5.00mm001
SW_SPST_B3U-1000P-B
SW_SPST_B3U-1000P-B001
PinHeader_1x15_P2.54mm_Vertical
PinHeader_1x15_P2.54mm_Vertical001
USB_Micro-B_Molex_47346-0001
LED_1206_3216Metric
LED_1206_3216Metric001
CP_EIA-2012-15_AVX-P
SOT-223
R_0603_1608Metric
R_0603_1608Metric001
R_0603_1608Metric002
SOT-23
SOT-224
R_0603_1608Metric003
R_0603_1608Metric004
C_0603_1608Metric
D_0603_1608Metric
R_0603_1608Metric005
R_0603_1608Metric006
R_0603_1608Metric007
R_0603_1608Metric008
R_0603_1608Metric009
QFN-28-1EP_5x5mm_P0.5mm_EP3.35x3.35mm
R_0603_1608Metric010
R_0603_1608Metric011
C_0603_1608Metric001
C_0603_1608Metric002
ESP32-WROOM-32
esp32-devkit-v1_30Pin
PinHeader_1x02_P2.54mm_Vertical
D_T-1_P12.70mm_Horizontal001
PinHeader_1x02_P2.54mm_Vertical001
terminal-case001
terminal002
terminal003
R_Axial_DIN0207_L6.3mm_D2.5mm_P10.16mm_Horizontal001
D_T-1_P12.70mm_Horizontal002
D_T-1_P2.54mm_Vertical_KathodeUp
R_Axial_DIN0207_L6.3mm_D2.5mm_P10.16mm_Horizontal002
terminal-case002
terminal004
terminal005
R_Axial_DIN0207_L6.3mm_D2.5mm_P10.16mm_Horizontal003
C_Disc_D7.0mm_W2.5mm_P5.00mm002
CP_Radial_D10.0mm_P5.00mm
R_Axial_DIN0207_L6.3mm_D2.5mm_P10.16mm_Horizontal004
TO-220-3_Vertical
PinHeader_1x01_P2.54mm_Vertical
TO-220-3_Vertical001
housing
pins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

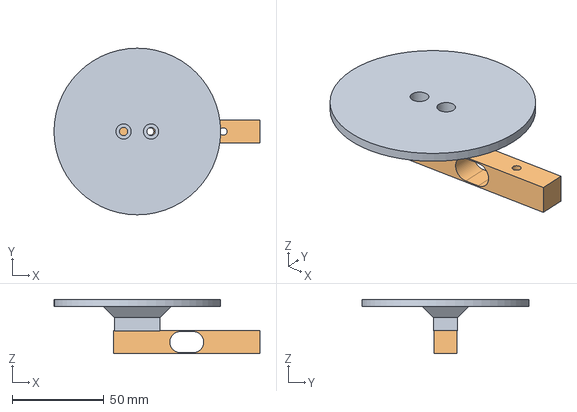
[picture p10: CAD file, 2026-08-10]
cad/parts/weigh-plate.FCStd
112.5 x 91.0 x 29.7 mm
plate-top
load-cell

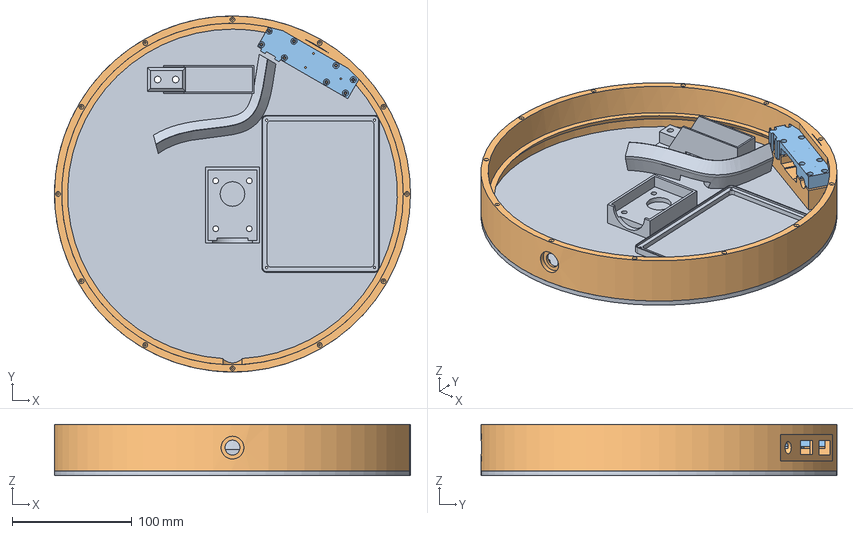
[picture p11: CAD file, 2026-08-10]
cad/parts/base.FCStd
297.0 x 297.0 x 42.8 mm
ring
connector-clamp

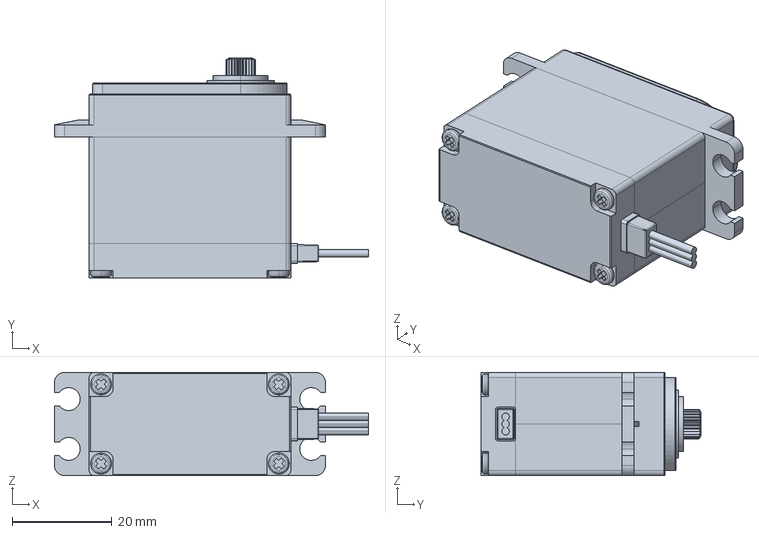
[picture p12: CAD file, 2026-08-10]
cad/parts/servo-motor.FCStd
63.1 x 44.3 x 20.7 mm

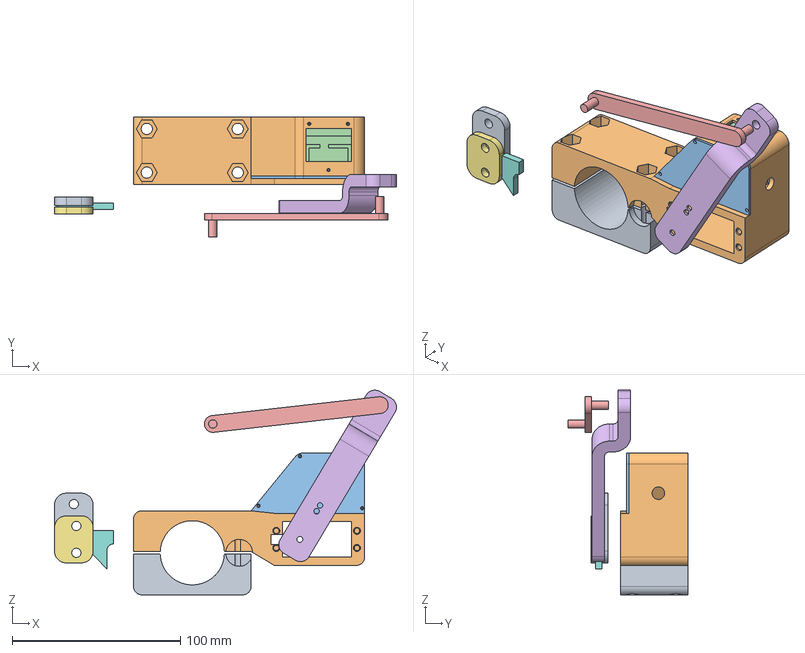
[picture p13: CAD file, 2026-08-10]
cad/parts/servo-mount.FCStd
203.5 x 71.2 x 121.8 mm
clamp-bot
clamp-top-servo
ui-lid
display-frame
lever-bucket
lever-motor_V2
front-clamp
gate
back-clamp

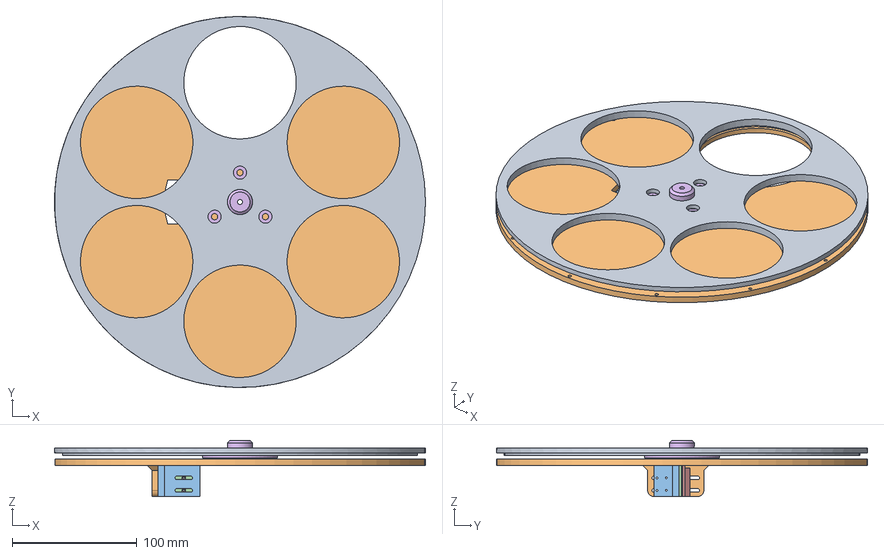
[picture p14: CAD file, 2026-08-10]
cad/parts/carousel.FCStd
297.0 x 297.0 x 45.0 mm
disk
base-plate
reed_angle
reed_mount_clamp
reed_mount_base

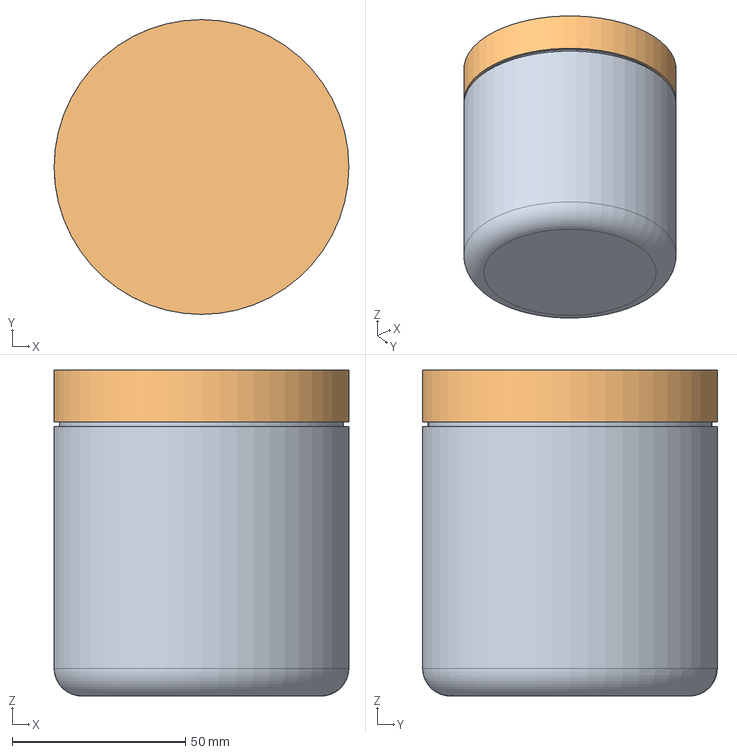
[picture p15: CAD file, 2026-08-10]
cad/parts/jar.FCStd
85.0 x 85.0 x 94.0 mm
glass
lid

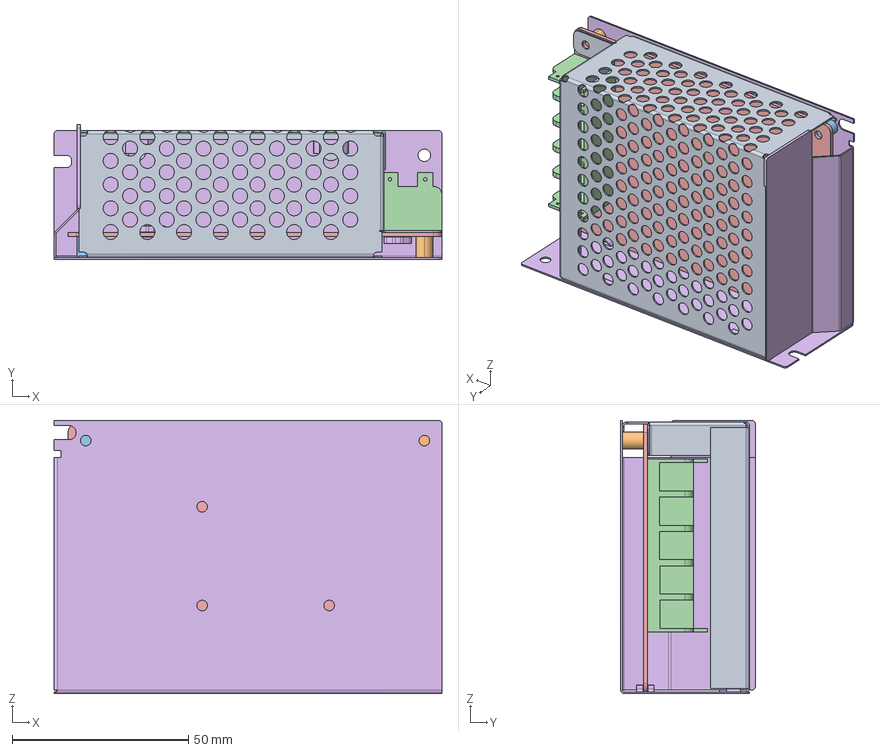
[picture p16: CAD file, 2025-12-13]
cad/parts/power-supply_12V.FCStd
110.0 x 38.2 x 77.5 mm
12V-5A Model S
12V-5A Model S001
12V-5A Model S002
12V-5A Model S003
12V-5A Model S004
12V-5A Model S005

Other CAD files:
cad/honey-jar-filler_asm.FCStd

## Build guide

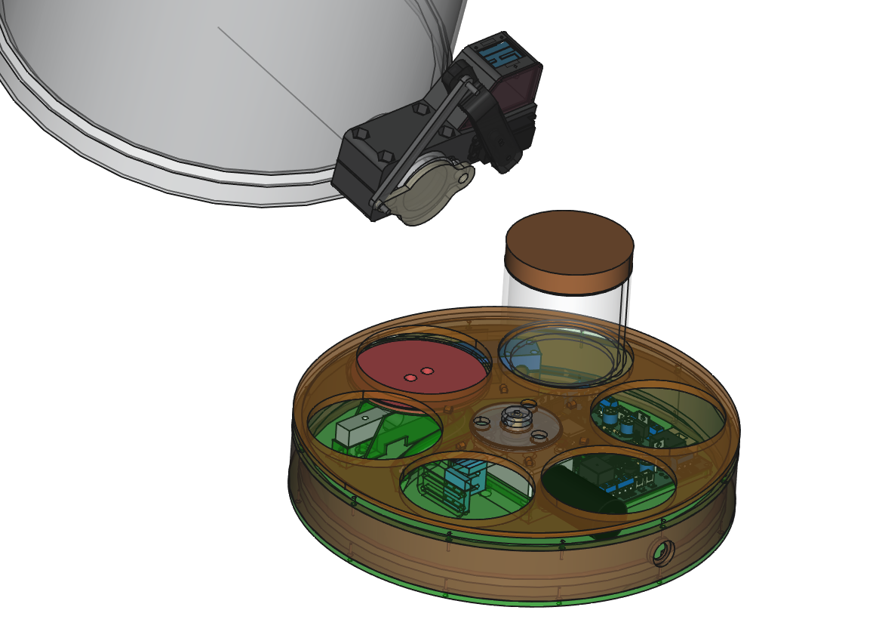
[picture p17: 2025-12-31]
cad/exports/screenshots/assembly.png

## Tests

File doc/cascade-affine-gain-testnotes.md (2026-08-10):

# Flow-cascade: affine gain rework — what changed & what to test

Context for future-me: worked on this ~2026-07-08..10 after the first hardware
cascade run (`data/telemetry/2026.07.05_21:00-x-dunkler-honig_cascade_ratereduced-learnfromoverfill/`).
That run showed 3 problems: overfill every fill (+15..23 g), gate stayed ~full
open until the very end (no visible slowdown), and the model prediction drifted
*worse* over successive fills. This commit is the fix. UNTESTED on hardware.

## What changed on a logical level

1. **Plant model: 6-point breakpoint schedule → affine `rate = K·gate + b`.**
   - Old: tried to learn a rate value at each of 10/20/…/90 % gate and
     interpolate. Dead idea — the controller only ever visits 2 gate regimes
     (fast phase high, terminal phase low), so the middle breakpoints never got
     data and stayed at defaults. The "effective gain" sampled at 60 % then slid
     around on a curve that never moved → the apparent K-drift 0.59→0.29.
   - New: one slope `K` + one offset `b`. `b` matters because flow onset is
     ~15 % gate (line does NOT pass through origin); forcing b=0 is what made a
     single scalar gain unstable across the range. `b` clamped [-60, +15] g/s,
     usually negative.
   - Learned live from **two EWMA operating points**: fast phase feeds the
     high-gate point, slow/terminal phase feeds the low-gate point. Refit
     (`cascade_refit_gain`) every update if the two gates are ≥ 8 % apart; else
     hold K and only re-solve b. In-fill alpha 0.15 (aggressive). Updates ONLY
     when gate stable past dead_time + settle margin (true steady state).
   - Persisted per preset across fills via signed-safe `learn_ewma` (K and b).
   - Feedforward is now `gate = (ṁ* − b) / K`; start gate + on_enter seeding use
     the same inversion. Seed at fill start: hi point = (60 %, K·60+b),
     lo point = (30 %, K·30+b) from the persisted entry.
   - NOTE seed `entry->gain_b = 0.0f` in `cascade_defaults_from_params` — first
     fill starts as pure linear-through-origin, so early feedforward will run a
     bit rich at low gates until b is learned. Expected; converges fast.

2. **Overfill fix (close threshold).** Root cause: `close_max` clamp collapsed
   to 10 g (`max(close_remaining_g*1.8, 10)` with close_remaining_g=5) while the
   computed `predicted_remaining` was 71–82 g → gate closed way too late.
   - Removed a double-count: `predicted_remaining_g = learned_post_close_gain_g`
     only (post_close already includes the in-flight mass; the old code also
     added dead_time·close_rate on top).
   - New clamp: `close_max = min( max(close_remaining*1.8, 10, post_close*1.5+15),
     target*0.6 )`.
   - post_close seed raised to `max(close_remaining*0.55, target*0.025)`.

3. **Flat profile fix (no visible slowdown).** fast_rate and slow_rate had both
   collapsed to ~30 g/s, so the taper was flat. Terminal rate is now decoupled
   from the learned slow_rate: `terminal = clamp(fast * 0.25, floor, fast)`
   (CASC_TERMINAL_RATE_FRAC=0.25). Profile tapers fast→terminal over the decel
   band.

## What to watch / test on hardware next

Flash this, run the same dark-honey preset, capture telemetry, then in the chart:

- [ ] **Overfill gone?** fill_error should land within ~±5 g from fill 2 on
      (fill 1 may still miss while b/post_close seed). Old run was +15..23 g.
- [ ] **Visible deceleration?** Gate should ramp down through a terminal crawl,
      not stay pinned high until close. Look at the gate trace + `target_rate`
      (ṁ*) taper in the rate panel.
- [ ] **K stable, not drifting?** `gate_gain_gps_per_pct` should settle and stay
      put across fills instead of sliding down. Also check `b` (new) goes
      negative and plausible (~ -K·onset%, e.g. onset 15 % → b ≈ -0.3·15 ≈ -4).
- [ ] **Two operating points separating?** The refit needs ≥ 8 % gate separation
      between fast and slow phases. If the fill never really slows (gate hi==lo),
      K holds and only b moves — check the fill actually enters slow_control
      phase (`near_close_logged`).
- [ ] **Feedforward sane at start?** `control_gate_cmd_pct` at fill open should
      invert to a reasonable opening, not slam to ceiling or to ~0.
- [ ] **Smith predictor:** ŷ_d (`model_delayed_gps`) should track measured rate
      once flow starts; ŷ (`model_rate_gps`) leads it by dead_time. PI
      integrator (`control_integ_pct`) should not rail.

## Still uncommitted / not done here (host tool side)
- `plot_runs.py`: `model_rate` overlay in the rate panel is done & verified, but
  the separate `_plot_control_panel` (rate error, prediction error, PI
  integrator) is written yet NOT wired into the gridspec / render path. Finish
  that wiring before relying on the control panel. Commit as `TOOL:` separately.

Key constants (in `filler_strategy_flow_cascade.c`): CASC_GAIN_B_MIN/MAX,
CASC_GAIN_MIN_GATE_SEP_PCT (8), CASC_GAIN_LIVE_ALPHA (0.15),
CASC_TERMINAL_RATE_FRAC (0.25), CASC_GAIN_SETTLE_MARGIN_S.

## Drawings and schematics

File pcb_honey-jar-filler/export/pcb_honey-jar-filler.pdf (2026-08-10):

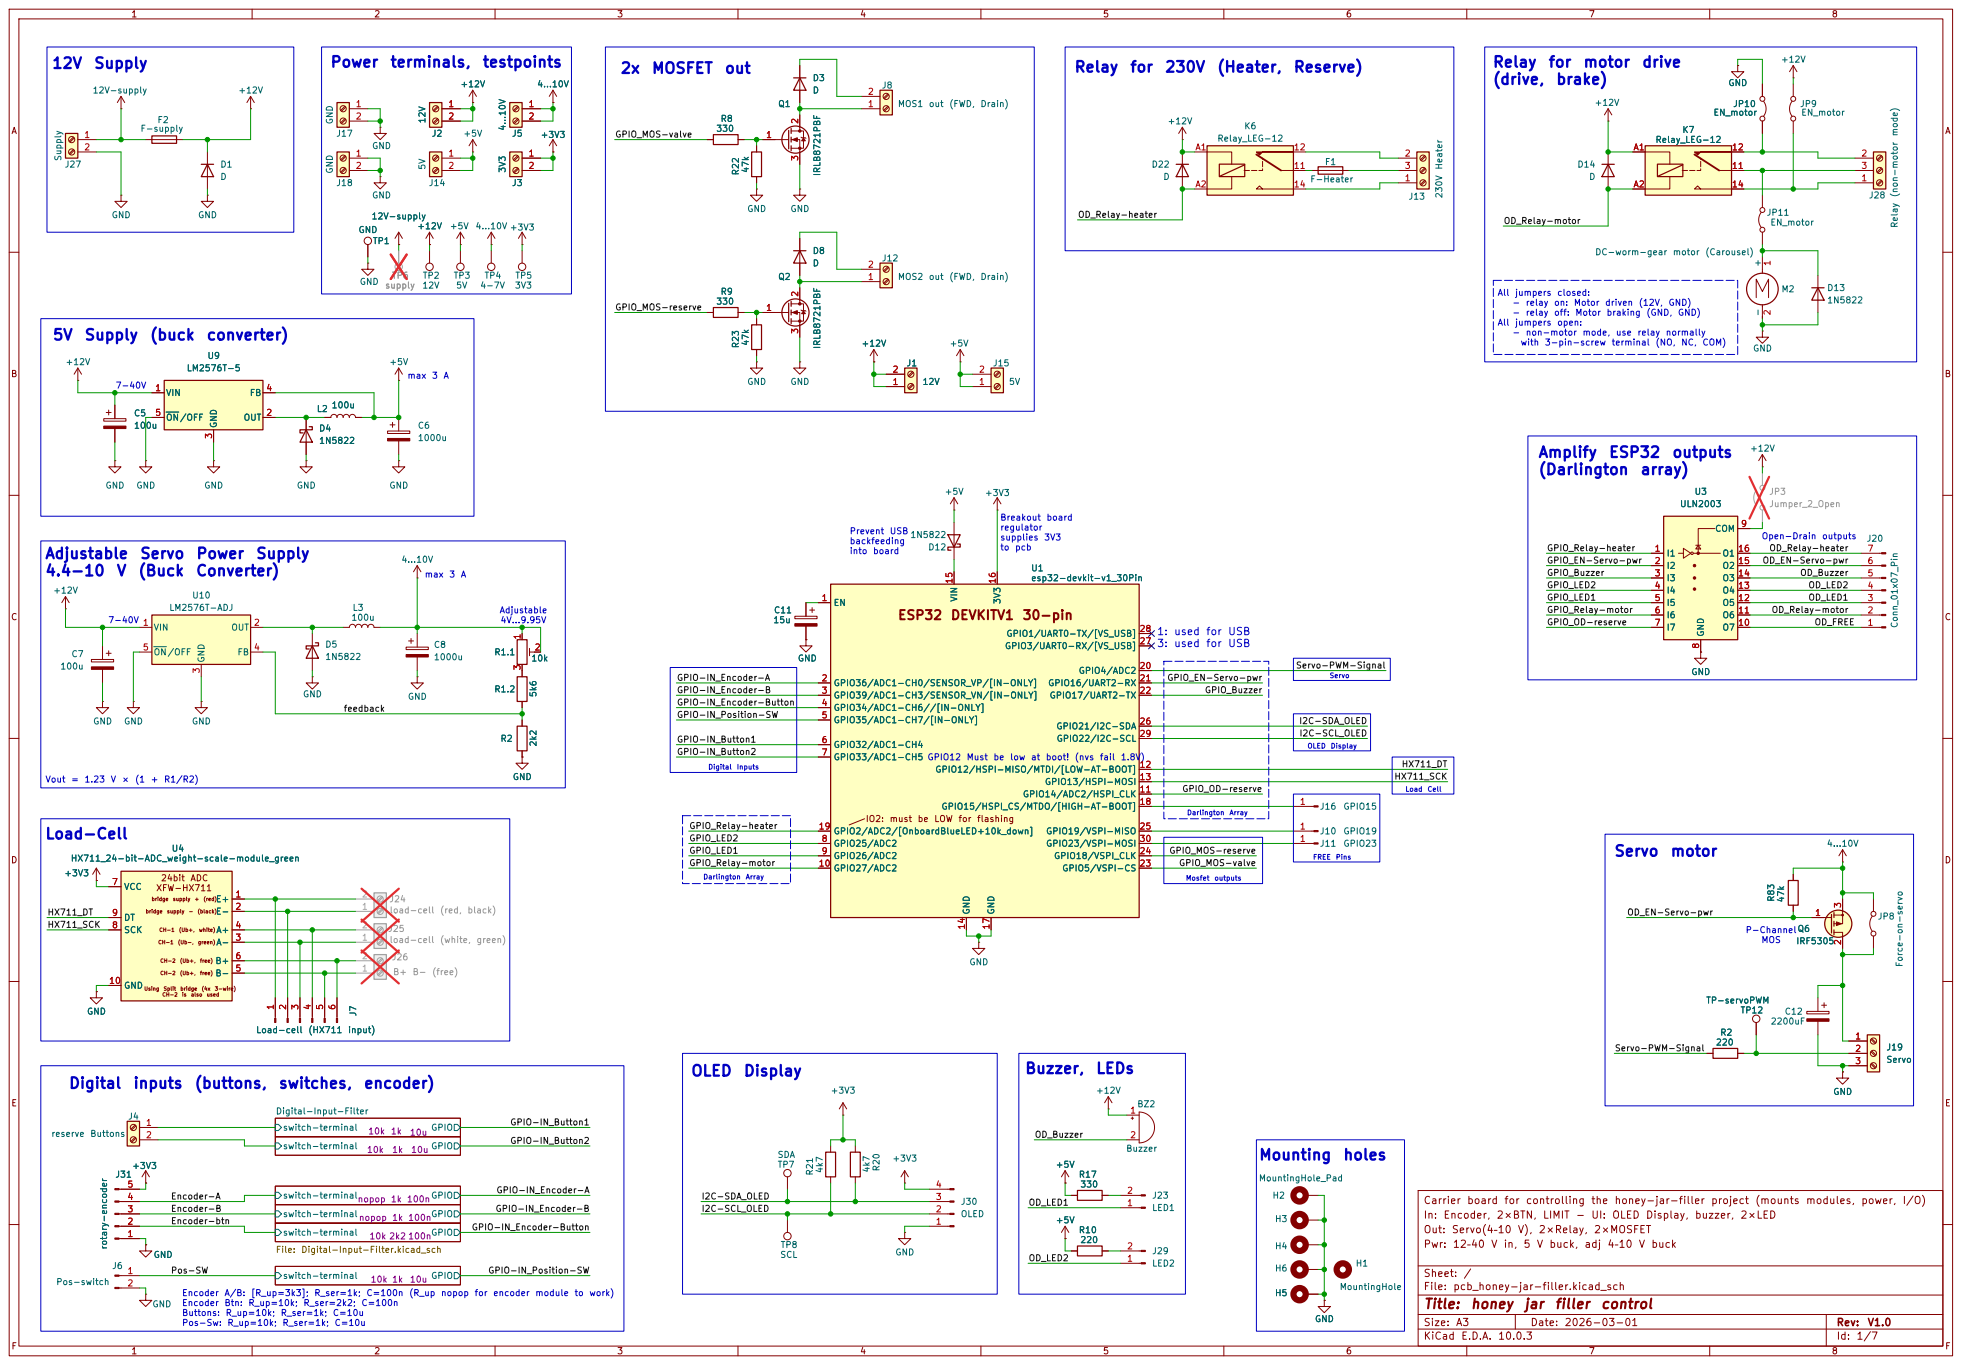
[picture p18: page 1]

(drive, brake) 2x MOSFET out

J28 Relay (non-motor mode)JP9

2 M2 DC-worm-gear motor (Carousel) TP5

supply
All jumpers closed: - relay on: Motor driven (12V, GND) - relay off: Motor braking (GND, GND) All jumpers open: - non-motor mode, use relay normally with 3-pin-screw terminal (NO, NC, COM) max 3 A

to pcb Digital inputs (buttons, switches, encoder)
3: used for USB Adjustable Servo Power Supply
4.4-10 V (Buck Converter)

IO2: must be LOW for flashing ESP32 DEVKITV1 30-pin

Servo-PWM-Signal Encoder-B

load-cell (white, green)

Digital-Input-Filter File: Digital-Input-Filter.kicad_sch 10k 1k 10u

Pwr: 12–40 V in, 5 V buck, adj 4–10 V buck Out: Servo(4–10 V), 2×Relay, 2×MOSFET

Id: 1/7 Title: honey jar filler control File: pcb_honey-jar-filler.kicad_sch Sheet: /

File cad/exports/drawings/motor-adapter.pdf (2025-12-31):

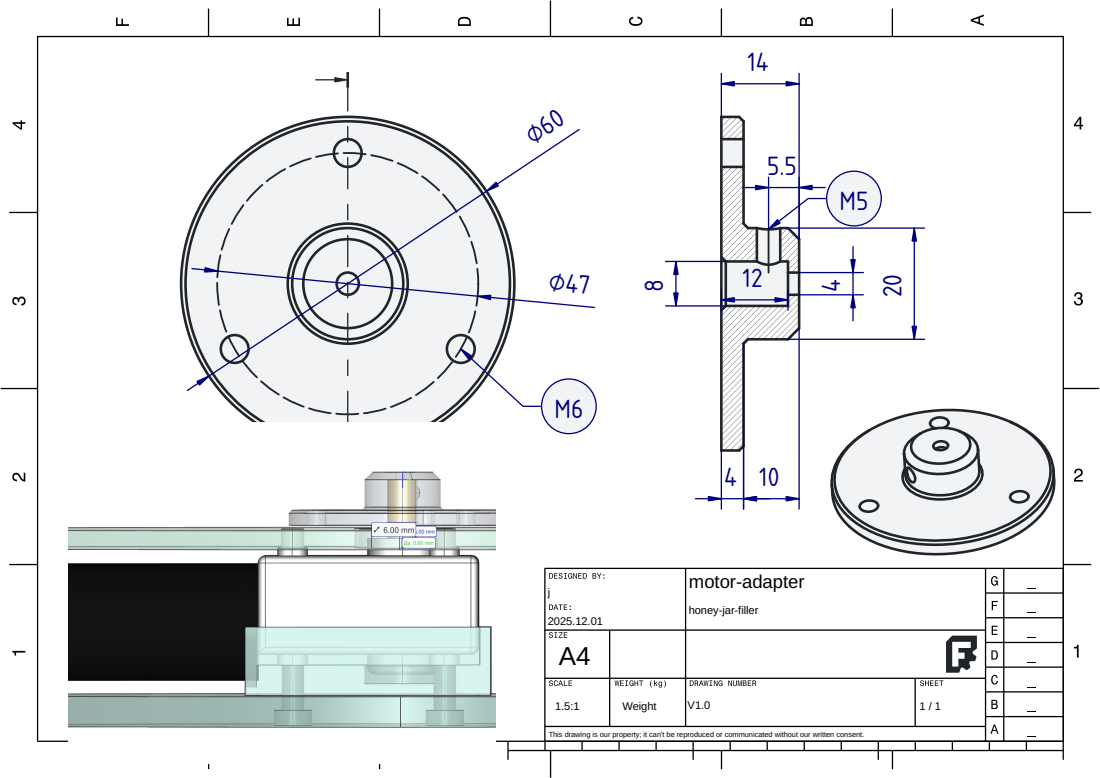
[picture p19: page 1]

j 2025.12.01 | motor-adapter honey-jar-filler

1.5:1 | Weight | V1.0 | 1 / 1

This drawing is our property; it can't be reproduced or communicated without our written consent.

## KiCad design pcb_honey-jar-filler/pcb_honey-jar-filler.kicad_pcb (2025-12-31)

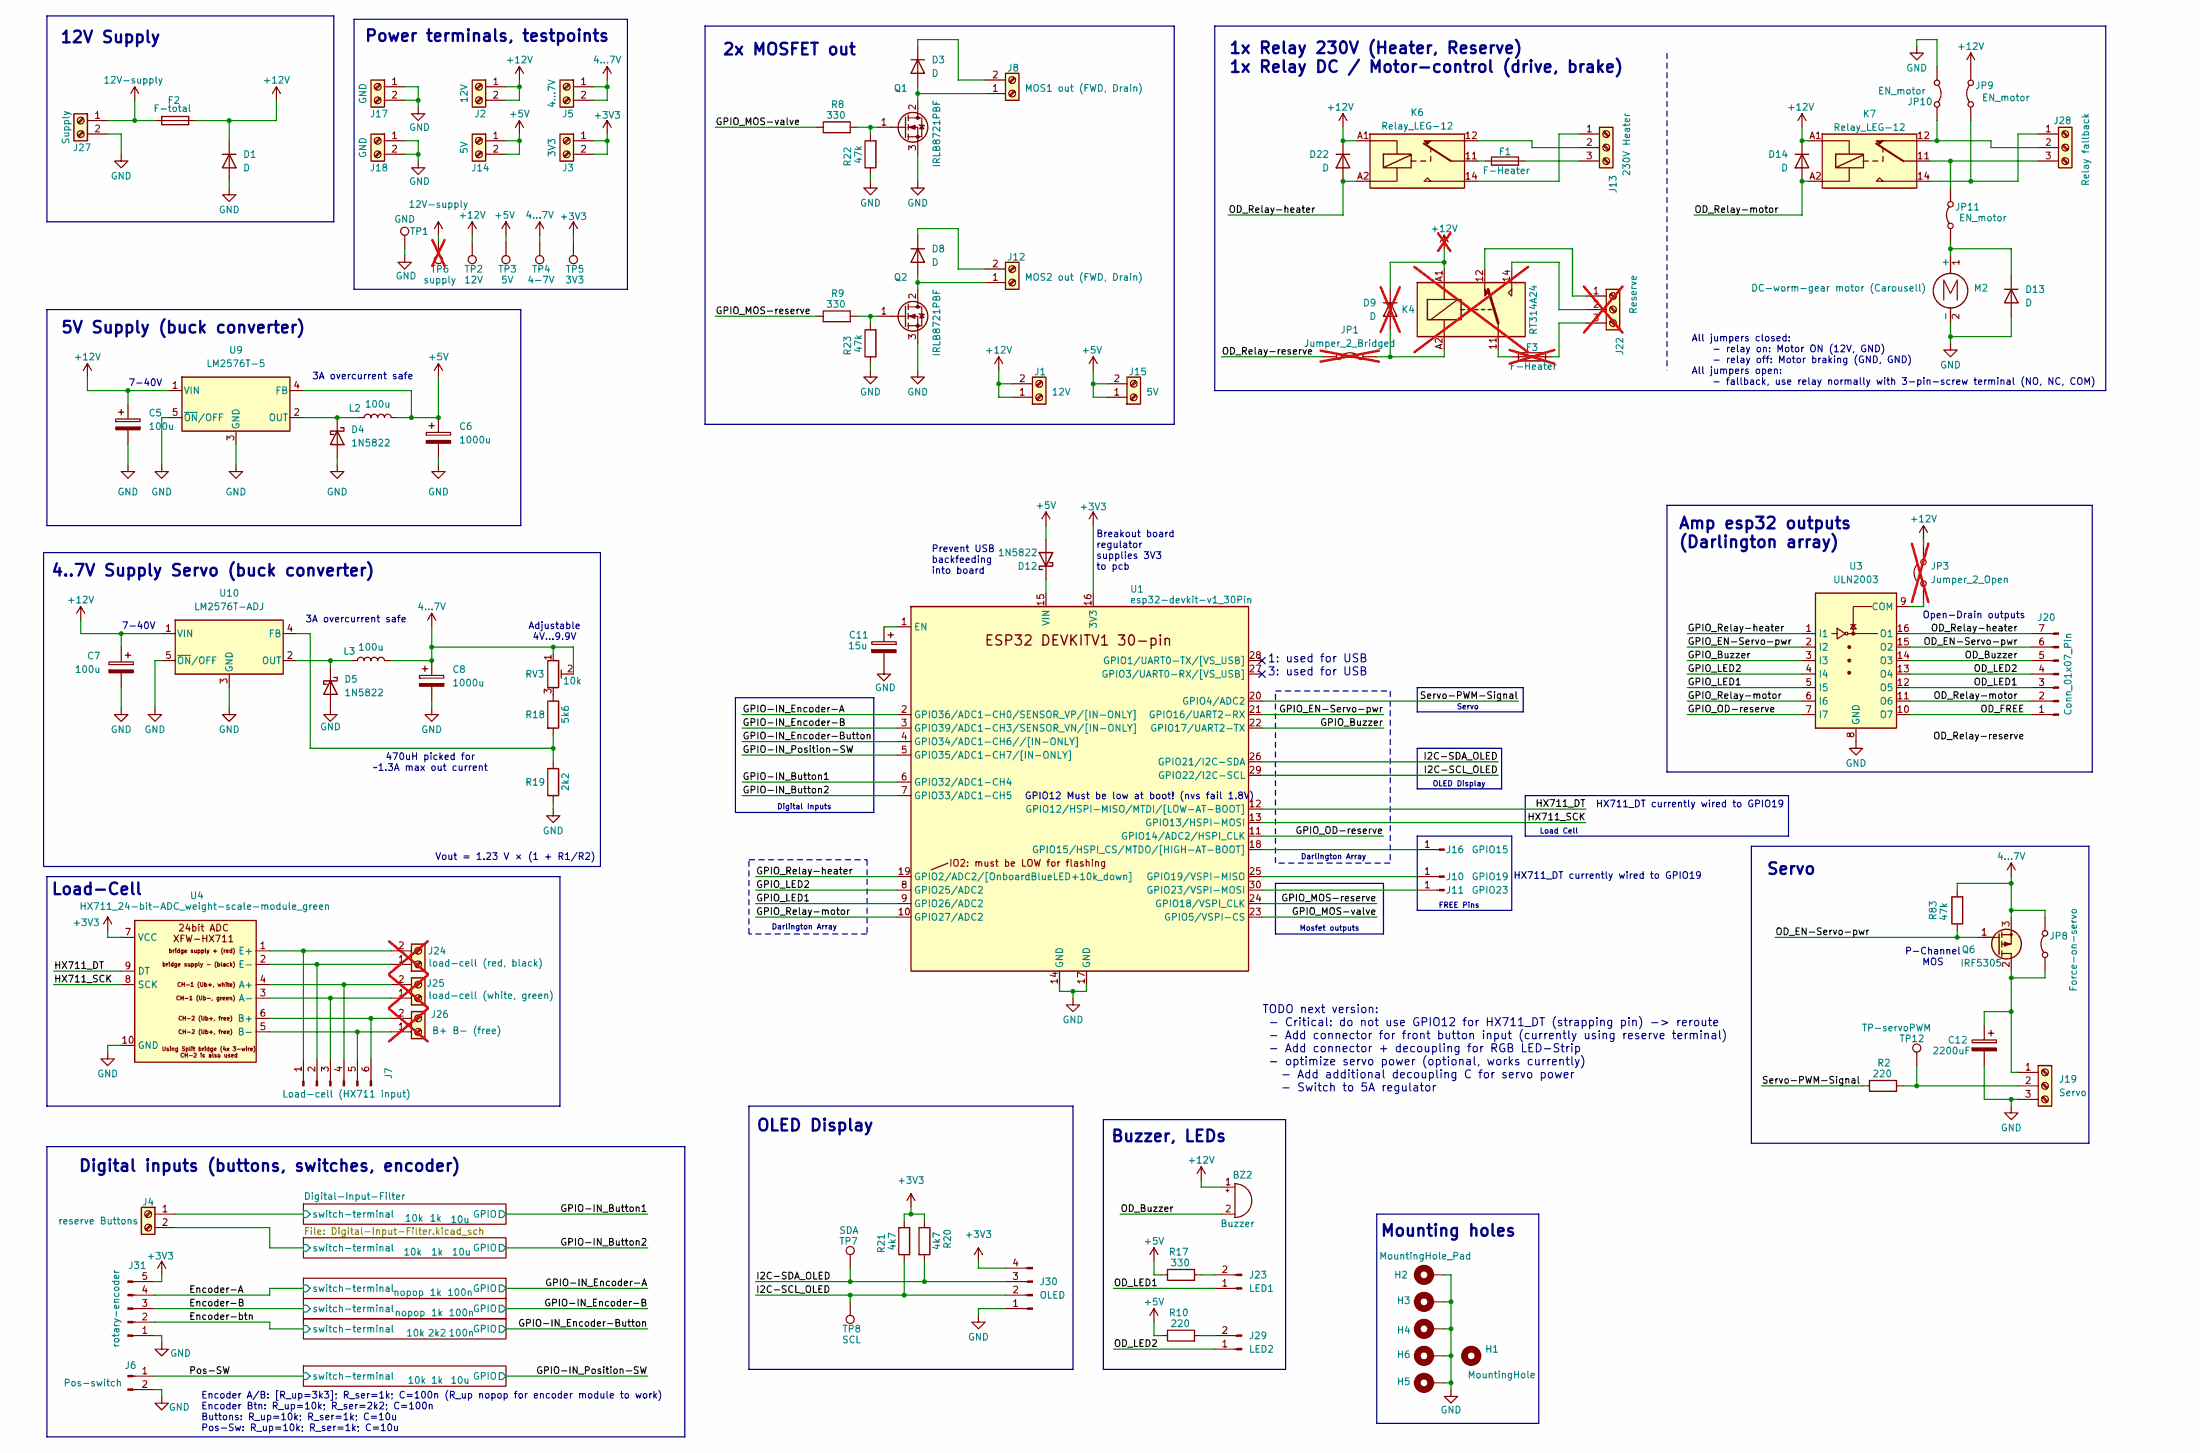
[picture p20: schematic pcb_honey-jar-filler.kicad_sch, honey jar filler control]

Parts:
BZ2: Buzzer; Buzzer_TDK_PS1240P02BT_D12.2mm_H6.5mm
C5, C7: 100u; CP_Radial_D8.0mm_P5.00mm
C6, C8: 1000u; CP_Radial_D10.0mm_P5.00mm
C11: 15u; CP_Radial_D6.3mm_P2.50mm
C12: 2200uF; CP_Radial_D10.0mm_P5.00mm
D1, D3, D8, D22: D; D_T-1_P12.70mm_Horizontal
D4, D12: 1N5822; D_DO-201AD_P15.24mm_Horizontal
D5: 1N5822; D_DO-201AE_P5.08mm_Vertical_AnodeUp
D9: D; D_T-1_P12.70mm_Horizontal; not fitted
D13, D14: D; D_T-1_P2.54mm_Vertical_KathodeUp
F1: F-Heater; Fuseholder_Cylinder-5x20mm_Stelvio-Kontek_PTF78_Horizontal_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
F2: F-total; Fuseholder_Automotive-Mini_Fuse11x4x16_Footprint15x5_Inline
F3: F-Heater; Fuseholder_Automotive-Mini_Fuse11x4x16_Footprint15x5_Inline; not fitted
H1: MountingHole; MountingHole_3mm
H2, H3, H4, H5, H6: MountingHole_Pad; MountingHole_2.2mm_NPTH-with-pad_DRC-clearance-error
J1, J2: 12V; ScrewTerminal_P5mm_2Pin_FP10x8
J3: 3V3; ScrewTerminal_P5mm_2Pin_FP10x8
J4: reserve Buttons; ScrewTerminal_P3.5mm_2Pin_FP7x7
J5: 4...7V; ScrewTerminal_P5mm_2Pin_FP10x8
J6: Pos-switch; JST_XH_B2B-XH-A_1x02_P2.50mm_Vertical
J7: Load-cell (HX711 input); JST_XH_B6B-XH-A_1x06_P2.50mm_Vertical
J8: MOS1 out (FWD, Drain); ScrewTerminal_P5mm_2Pin_FP10x8
J10: GPIO19; PinHeader_1x01_P2.54mm_Vertical
J11: GPIO23; PinHeader_1x01_P2.54mm_Vertical
J12: MOS2 out (FWD, Drain); ScrewTerminal_P5mm_2Pin_FP10x8
J13: 230V Heater; ScrewTerminal_P5mm_3Pin_FP15x8
J14, J15: 5V; ScrewTerminal_P5mm_2Pin_FP10x8
J16: GPIO15; PinHeader_1x01_P2.54mm_Vertical
J17, J18: GND; ScrewTerminal_P5mm_2Pin_FP10x8
J19: Servo; ScrewTerminal_P5mm_3Pin_FP15x8
J20: Conn_01x07_Pin; PinHeader_1x07_P2.54mm_Vertical
J22: Reserve; ScrewTerminal_P5mm_3Pin_FP15x8; not fitted
J23: LED1; JST_XH_B2B-XH-A_1x02_P2.50mm_Vertical
J24: load-cell (red, black); ScrewTerminal_P3.5mm_2Pin_FP7x7; not fitted
J25: load-cell (white, green); ScrewTerminal_P3.5mm_2Pin_FP7x7; not fitted
J26: B+ B- (free); ScrewTerminal_P3.5mm_2Pin_FP7x7; not fitted
J27: Supply; ScrewTerminal_P5mm_2Pin_FP10x8
J28: Relay fallback; ScrewTerminal_P5mm_3Pin_FP15x8
J29: LED2; JST_XH_B2B-XH-A_1x02_P2.50mm_Vertical
J30: OLED; JST_XH_B4B-XH-A_1x04_P2.50mm_Vertical
J31: rotary-encoder; JST_XH_B5B-XH-A_1x05_P2.50mm_Vertical
JP1: Jumper_2_Bridged; PinHeader_1x02_P2.54mm_Vertical; not fitted
JP3: Jumper_2_Open; PinHeader_1x02_P2.54mm_Vertical; not fitted
JP8: Force-on-servo; PinHeader_1x02_P2.54mm_Vertical
JP9, JP10, JP11: EN_motor; PinHeader_1x02_P2.54mm_Vertical
K4: RT314A24; Relay_SPDT_Schrack-RT1-16A-FormC_RM5mm; not fitted
K6, K7: Relay_LEG-12; Relay_LEG-xxF
L2, L3: 100u; L_Toroid_Vertical_L14.0mm_W6.3mm_P4.57mm_Pulse_A
M2: DC-worm-gear motor (Carousell); ScrewTerminal_P5mm_2Pin_FP10x8
Q1, Q2: IRLB8721PBF; TO-220-3_Vertical
Q6: IRF5305; TO-220-3_Vertical
R2, R10: 220; R_Axial_DIN0207_L6.3mm_D2.5mm_P10.16mm_Horizontal
R8, R9, R17: 330; R_Axial_DIN0207_L6.3mm_D2.5mm_P10.16mm_Horizontal
R18: 5k6; R_Axial_DIN0207_L6.3mm_D2.5mm_P10.16mm_Horizontal
R19: 2k2; R_Axial_DIN0207_L6.3mm_D2.5mm_P10.16mm_Horizontal
R20: 4k7; R_Axial_DIN0204_L3.6mm_D1.6mm_P2.54mm_Vertical
R21: 4k7; R_Axial_DIN0207_L6.3mm_D2.5mm_P10.16mm_Horizontal
R22, R23, R83: 47k; R_Axial_DIN0207_L6.3mm_D2.5mm_P10.16mm_Horizontal
RV3: 10k; Potentiometer_Piher_PT-10-V10_Vertical
TP1: GND; PinHeader_1x01_P2.54mm_Vertical
TP2: 12V; PinHeader_1x01_P2.54mm_Vertical
TP3: 5V; PinHeader_1x01_P2.54mm_Vertical
TP4: 4-7V; PinHeader_1x01_P2.54mm_Vertical
TP5: 3V3; PinHeader_1x01_P2.54mm_Vertical
TP6: supply; PinHeader_1x01_P2.54mm_Vertical; not fitted
TP7: SDA; PinHeader_1x01_P2.54mm_Vertical
TP8: SCL; PinHeader_1x01_P2.54mm_Vertical
TP12: TP-servoPWM; PinHeader_1x01_P2.54mm_Vertical
U1: esp32-devkit-v1_30Pin
U3: ULN2003; DIP-16_W7.62mm_LongPads
U4: HX711_24-bit-ADC_weight-scale-module_green
U9: LM2576T-5; TO-220-5_P3.4x3.7mm_StaggerOdd_Lead3.8mm_Vertical
U10: LM2576T-ADJ; TO-220-5_P3.4x3.7mm_StaggerOdd_Lead3.8mm_Vertical

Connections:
4...7V: C8.1, J5.1, J5.2, JP8.2 (B), L3.2, Q6.3 (S), R83.2, RV3.1, RV3.2, TP4.1
12V-supply: F2.2, J27.1, TP6.1
+3V3: J3.1, J3.2, J30.4, J31.5, R20.1, R21.2, TP5.1, U1.16 (3V3), U4.7 (VCC); also elsewhere on the board
+5V: C6.1, D12.2 (A), J14.1, J14.2, J15.1, J15.2, L2.2, R10.1, R17.1, TP3.1, U9.4 (FB)
+12V: BZ2.1 (+), C5.1, C7.1, D1.1 (K), D9.1 (K), D14.1 (K), D22.1 (K), F2.1, J1.1, J1.2, J2.1, J2.2, JP3.2 (B), JP9.2 (B), K4.A1, K6.A1, K7.A1, TP2.1, U9.1 (VIN), U10.1 (VIN)
/Digital-Input-Filter1/switch-terminal: J4.2; also elsewhere on the board
/Digital-Input-Filter/switch-terminal: J4.1; also elsewhere on the board
/Encoder-A: J31.4; also elsewhere on the board
/Encoder-B: J31.3; also elsewhere on the board
/Encoder-btn: J31.2; also elsewhere on the board
/GPIO-IN_Button1: U1.6 (GPIO32/ADC1-CH4); also elsewhere on the board
/GPIO-IN_Button2: U1.7 (GPIO33/ADC1-CH5); also elsewhere on the board
/GPIO-IN_Encoder-A: U1.2 (GPIO36/ADC1-CH0/SENSOR_VP/[IN-ONLY]); also elsewhere on the board
/GPIO-IN_Encoder-B: U1.3 (GPIO39/ADC1-CH3/SENSOR_VN/[IN-ONLY]); also elsewhere on the board
/GPIO-IN_Encoder-Button: U1.4 (GPIO34/ADC1-CH6//[IN-ONLY]); also elsewhere on the board
/GPIO-IN_Position-SW: U1.5 (GPIO35/ADC1-CH7/[IN-ONLY]); also elsewhere on the board
/GPIO_Buzzer: U1.22 (GPIO17/UART2-TX), U3.3 (I3)
/GPIO_EN-Servo-pwr: U1.21 (GPIO16/UART2-RX), U3.2 (I2)
/GPIO_LED1: U1.9 (GPIO26/ADC2), U3.5 (I5)
/GPIO_LED2: U1.8 (GPIO25/ADC2), U3.4 (I4)
/GPIO_MOS-reserve: R9.1, U1.24 (GPIO18/VSPI_CLK)
/GPIO_MOS-valve: R8.1, U1.23 (GPIO5/VSPI-CS)
/GPIO_OD-reserve: U1.11 (GPIO14/ADC2/HSPI_CLK), U3.7 (I7)
/GPIO_Relay-heater: U1.19 (GPIO2/ADC2/[OnboardBlueLED+10k_down]), U3.1 (I1)
/GPIO_Relay-motor: U1.10 (GPIO27/ADC2), U3.6 (I6)
/HX711_DT: U1.12 (GPIO12/HSPI-MISO/MTDI/[LOW-AT-BOOT]), U4.9 (DT)
/HX711_SCK: U1.13 (GPIO13/HSPI-MOSI), U4.8 (SCK)
/I2C-SCL_OLED: J30.2, R21.1, TP8.1, U1.29 (GPIO22/I2C-SCL)
/I2C-SDA_OLED: J30.3, R20.2, TP7.1, U1.26 (GPIO21/I2C-SDA)
/OD_Buzzer: BZ2.2 (-), J20.5, U3.14 (O3)
/OD_EN-Servo-pwr: J20.6, Q6.1 (G), R83.1, U3.15 (O2)
/OD_FREE: J20.1, U3.10 (O7)
/OD_LED1: J20.3, J23.1, U3.12 (O5)
/OD_LED2: J20.4, J29.1, U3.13 (O4)
/OD_Relay-heater: D22.2 (A), J20.7, K6.A2, U3.16 (O1)
/OD_Relay-motor: D14.2 (A), J20.2, K7.A2, U3.11 (O6)
/Pos-SW: J6.1; also elsewhere on the board
/Servo-PWM-Signal: R2.1, U1.20 (GPIO4/ADC2)
GND: C5.2, C6.2, C7.2, C8.2, C11.2, C12.2, D1.2 (A), D4.2 (A), D5.2 (A), D13.2 (A), H2.1, H3.1, H4.1, H5.1, H6.1, J6.2, J17.1, J17.2, J18.1, J18.2, J19.3, J27.2, J30.1, J31.1, JP10.1 (A), M2.2 (-), Q1.3 (S), Q2.3 (S), R19.2, R22.1, R23.1, TP1.1, U1.14 (GND), U1.17 (GND), U3.8 (GND), U4.10 (GND), U9.3 (GND), U9.5 (~ON/OFF), U10.3 (GND), U10.5 (~ON/OFF); also elsewhere on the board
unnamed: D3.2 (A), J8.1, Q1.2 (D)
unnamed: D3.1 (K), J8.2
unnamed: D4.1 (K), L2.1, U9.2 (OUT)
unnamed: D5.1 (K), L3.1, U10.2 (OUT)
unnamed: D8.2 (A), J12.1, Q2.2 (D)
unnamed: D8.1 (K), J12.2
unnamed: D9.2 (A), JP1.2 (B), K4.A2
unnamed: D12.1 (K), U1.15 (VIN)
unnamed: D13.1 (K), JP11.1 (A), M2.1 (+)
unnamed: F1.1, K6.11
unnamed: F3.1, K4.11
unnamed: F3.2, J22.3
unnamed: J7.1, J24.2, U4.1 (E+)
unnamed: J7.2, J24.1, U4.2 (E-)
unnamed: J7.3, J25.1, U4.3 (A-)
unnamed: J7.4, J25.2, U4.4 (A+)
unnamed: J7.5, J26.1, U4.5 (B-)
unnamed: J7.6, J26.2, U4.6 (B+)
unnamed: J10.1, U1.25 (GPIO19/VSPI-MISO)
unnamed: J11.1, U1.30 (GPIO23/VSPI-MOSI)
unnamed: J13.1, K6.14
unnamed: J13.2, K6.12
unnamed: F1.2, J13.3
unnamed: J16.1, U1.18 (GPIO15/HSPI_CS/MTDO/[HIGH-AT-BOOT])
unnamed: C12.1, J19.1, JP8.1 (A), Q6.2 (D)
unnamed: J19.2, R2.2, TP12.1
unnamed: J22.1, K4.12
unnamed: J22.2, K4.14
unnamed: J23.2, R17.2
unnamed: J28.1, JP9.1 (A), K7.14
unnamed: J28.2, JP10.2 (B), K7.12
unnamed: J28.3, JP11.2 (B), K7.11
unnamed: J29.2, R10.2
unnamed: Q1.1 (G), R8.2, R22.2
unnamed: Q2.1 (G), R9.2, R23.2
unnamed: R18.1, RV3.3
unnamed: C11.1, U1.1 (EN)
unnamed: JP3.1 (A), U3.9 (COM)
unnamed: R18.2, R19.1, U10.4 (FB)

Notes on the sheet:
470uH picked for ~1.3A max out current
3A overcurrent safe
Darlington Array
Digital Inputs
2x MOSFET out
5V Supply (buck converter)
GPIO12 Must be low at boot! (nvs fail 1.8V)
Power terminals, testpoints
Adjustable 4V...9.9V
TODO next version: - Critical: do not use GPIO12 for HX711_DT (strapping pin) -> reroute - Add connector for front button input (currently using reserve terminal) - Add connector + decoupling for RGB LED-Strip - optimize servo power (optional, works currently) - Add additional decoupling C for serv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
Encoder A/B: [R_up=3k3]; R_ser=1k; C=100n (R_up nopop for encoder module to work) Encoder Btn: R_up=10k; R_ser=2k2; C=100n Buttons: R_up=10k; R_ser=1k; C=10u Pos-Sw: R_up=10k; R_ser=1k; C=10u
Buzzer, LEDs
OLED Display
Breakout board regulator supplies 3V3 to pcb
Digital inputs (buttons, switches, encoder)
Load Cell
Mosfet outputs
4..7V Supply Servo (buck converter)
HX711_DT currently wired to GPIO19
1: used for USB 3: used for USB
Load-Cell
P-Channel MOS
1x Relay 230V (Heater, Reserve) 1x Relay DC / Motor-control (drive, brake)
Mounting holes
Open-Drain outputs
Vout = 1.23 V × (1 + R1/R2)
Amp esp32 outputs (Darlington array)
Servo
7-40V
12V Supply
Prevent USB backfeeding into board
FREE Pins
All jumpers closed: - relay on: Motor ON (12V, GND) - relay off: Motor braking (GND, GND) All jumpers open: - fallback, use relay normally with 3-pin-screw terminal (NO, NC, COM)

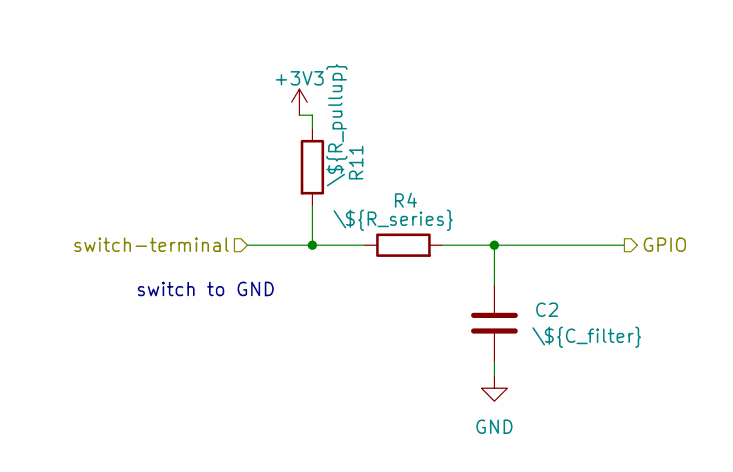
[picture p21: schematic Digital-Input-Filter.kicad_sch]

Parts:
C2: \${C_filter}; C_DualType__Disc-7.0x2.5mm-P5mm__Elko-D5mm-P2.5mm
R4: \${R_series}; R_Axial_DIN0207_L6.3mm_D2.5mm_P10.16mm_Horizontal
R11: \${R_pullup}; R_Axial_DIN0207_L6.3mm_D2.5mm_P10.16mm_Horizontal

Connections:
+3V3: R11.1; also elsewhere on the board
/Digital-Input-Filter/switch-terminal: R4.1, R11.2; also elsewhere on the board
/GPIO-IN_Button1: C2.1, R4.2; also elsewhere on the board
GND: C2.2; also elsewhere on the board

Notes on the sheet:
switch to GND

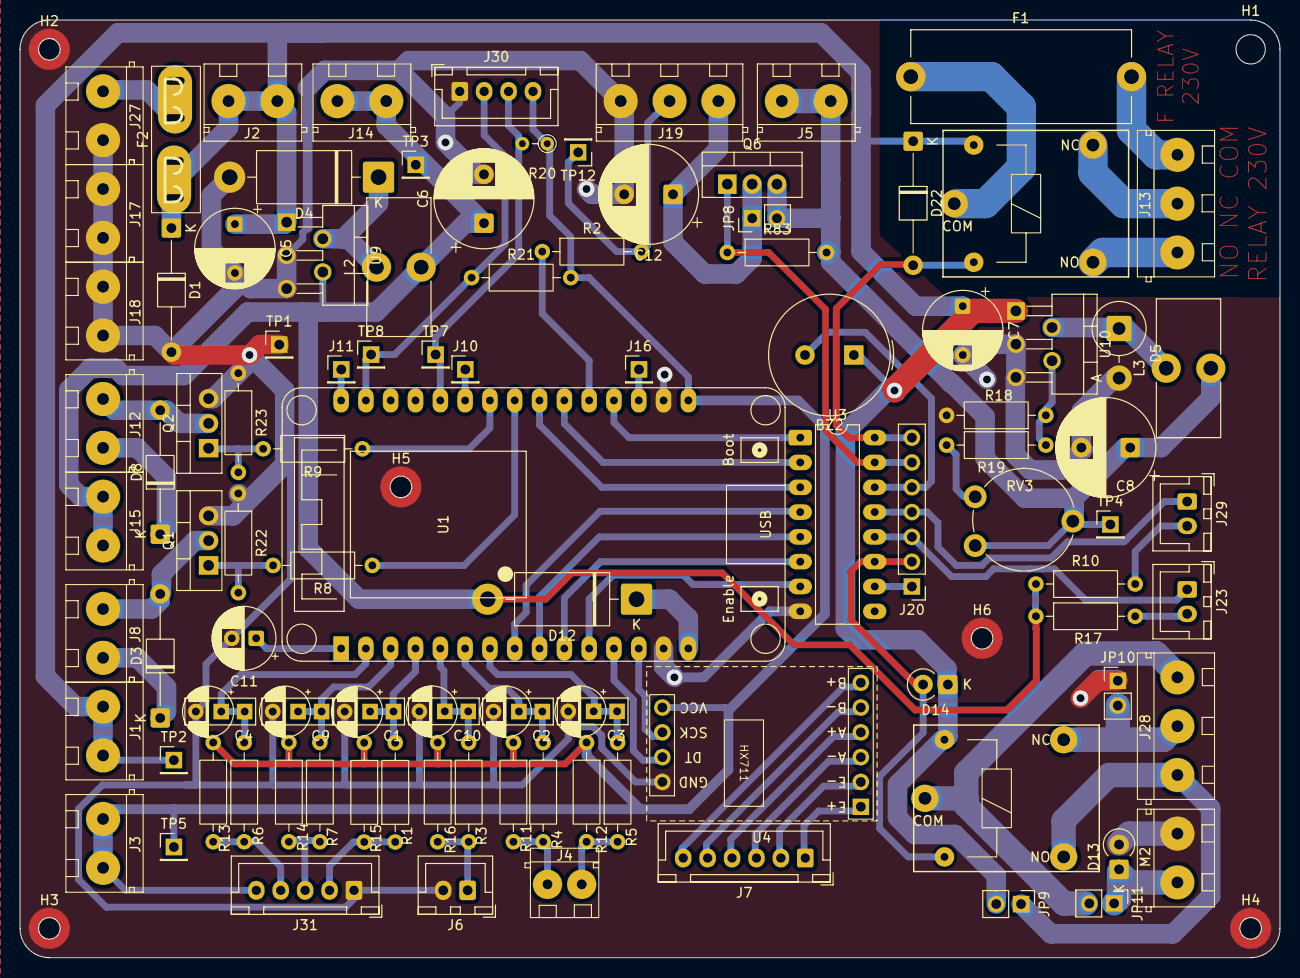
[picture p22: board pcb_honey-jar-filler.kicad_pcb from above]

Board: 2 copper layers, 129.0 x 96.0 mm, 105 parts (0 on the bottom side), 72 nets.

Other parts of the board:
C1, C4, C9: \100n; C_DualType__Disc-7.0x2.5mm-P5mm__Elko-D5mm-P2.5mm
C3, C10: \10u; C_DualType__Disc-7.0x2.5mm-P5mm__Elko-D5mm-P2.5mm
R1: \2k2; R_Axial_DIN0207_L6.3mm_D2.5mm_P10.16mm_Horizontal
R3, R5, R6, R7: \1k; R_Axial_DIN0207_L6.3mm_D2.5mm_P10.16mm_Horizontal
R12, R15, R16: \10k; R_Axial_DIN0207_L6.3mm_D2.5mm_P10.16mm_Horizontal
R13, R14: \nopop; R_Axial_DIN0207_L6.3mm_D2.5mm_P10.16mm_Horizontal

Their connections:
+3V3: R12.1, R13.1, R14.1, R15.1, R16.1; also elsewhere on the board
/Digital-Input-Filter1/switch-terminal: R5.1, R12.2; also elsewhere on the board
/Encoder-A: R6.1, R13.2; also elsewhere on the board
/Encoder-B: R7.1, R14.2; also elsewhere on the board
/Encoder-btn: R1.1, R15.2; also elsewhere on the board
/GPIO-IN_Button2: C3.1, R5.2; also elsewhere on the board
/GPIO-IN_Encoder-A: C4.1, R6.2; also elsewhere on the board
/GPIO-IN_Encoder-B: C9.1, R7.2; also elsewhere on the board
/GPIO-IN_Encoder-Button: C1.1, R1.2; also elsewhere on the board
/GPIO-IN_Position-SW: C10.1, R3.2; also elsewhere on the board
/Pos-SW: R3.1, R16.2; also elsewhere on the board
GND: C1.2, C3.2, C4.2, C9.2, C10.2; also elsewhere on the board

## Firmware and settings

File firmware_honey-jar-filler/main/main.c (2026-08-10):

#include <stdio.h>
#include "freertos/FreeRTOS.h"
#include "freertos/task.h"
#include "driver/gpio.h"
#include "driver/i2c_master.h"
#include "esp_log.h"
//#include "esp_rom_sys.h"
#include "sdkconfig.h"
#include "nvs_flash.h"
#include "nvs.h"
#include "encoder.h"
#include "ssd1306.h"
#include "led_strip.h"
#include "iot_servo.h"
#include "driver/ledc.h"
#include "motor.h"
#include "gate.h"
#include "ui_task.h"
#include "filler_fsm.h"
#include "buzzer.h"

#include "config.h"
#include "iotest.h"
#include "scale_hx711.h"
#include "app.h"
#include "telemetry.h"

static const char *TAG = "main";

#define CONFIG_TASK_PRIO_TELEMETRY 2
#define CONFIG_TASK_CORE_TELEMETRY tskNO_AFFINITY


static led_strip_handle_t s_strip;

static uint8_t ws2812_scale(uint8_t v)
{
    return (uint8_t)((v * CONFIG_WS2812_MAX_BRIGHTNESS_PCT) / 100);
}

static void ws2812_set_all(uint8_t r, uint8_t g, uint8_t b)
{
    if (!s_strip) return;
    r = ws2812_scale(r);
    g = ws2812_scale(g);
    b = ws2812_scale(b);
    for (int i = 0; i < CONFIG_WS2812_LED_COUNT; ++i) {
        led_strip_set_pixel(s_strip, i, r, g, b);
    }
    (void)led_strip_refresh(s_strip);
}

static void ws2812_clear(void)
{
    if (!s_strip) return;
    (void)led_strip_clear(s_strip);
}

// Probe the OLED before constructing the SSD1306 driver. The managed SSD1306
// component uses blocking I2C transfers during init, so probing first keeps
// startup from hanging on boards without the display attached.
static ssd1306_handle_t startup_init_display(void)
{
    i2c_master_bus_config_t bus_cfg = {
        .i2c_port = I2C_NUM_0,
        .sda_io_num = CONFIG_DISPLAY_SDA_GPIO,
        .scl_io_num = CONFIG_DISPLAY_SCL_GPIO,
        .clk_source = I2C_CLK_SRC_DEFAULT,
        .glitch_ignore_cnt = 7,
        .flags.enable_internal_pullup = true,
    };
    ssd1306_config_t cfg = {
        .bus = SSD1306_I2C,
        .width = 128,
        .height = 64,
        .iface.i2c = {
            .port = I2C_NUM_0,
            .addr = 0x3C,
            .rst_gpio = GPIO_NUM_NC,
        },
    };

    i2c_master_bus_handle_t bus_handle = NULL;
    ESP_LOGI(TAG, "startup: initializing I2C display bus");
    esp_err_t err = i2c_new_master_bus(&bus_cfg, &bus_handle);
    if (err != ESP_OK) {
        ESP_LOGW(TAG, "startup: I2C display bus init failed (%s)", esp_err_to_name(err));
        if (CONFIG_DISPLAY_REQUIRED) {
            ESP_ERROR_CHECK(err);
        }
        return NULL;
    }
    ESP_LOGI(TAG, "startup: I2C display bus ready");

    ESP_LOGI(TAG, "startup: probing OLED display");
    err = i2c_master_probe(bus_handle, cfg.iface.i2c.addr, CONFIG_DISPLAY_PROBE_TIMEOUT_MS);
    if (err != ESP_OK) {
        ESP_LOGW(TAG, "startup: OLED probe failed (%s)", esp_err_to_name(err));
        (void)i2c_del_master_bus(bus_handle);
        if (CONFIG_DISPLAY_REQUIRED) {
            ESP_ERROR_CHECK(err);
        }
        ESP_LOGW(TAG, "startup: continuing without display");
        return NULL;
    }

    ESP_LOGI(TAG, "startup: initializing OLED display");
    ssd1306_handle_t disp = NULL;
    err = ssd1306_new_i2c(&cfg, &disp);
    if (err != ESP_OK || !disp) {
        ESP_LOGW(TAG, "startup: OLED init failed (%s)", esp_err_to_name(err));
        (void)i2c_del_master_bus(bus_handle);
        if (CONFIG_DISPLAY_REQUIRED) {
            ESP_ERROR_CHECK(err != ESP_OK ? err : ESP_ERR_INVALID_STATE);
        }
        ESP_LOGW(TAG, "startup: continuing without display");
        return NULL;
    }

    ssd1306_clear(disp);
    ssd1306_draw_text(disp, 0, 0, "INITIALIZED", true);
    ssd1306_display(disp);
    ESP_LOGI(TAG, "startup: OLED display ready");

    return disp;
}

// Startup LED strip self-test (blocking, runs once).
static void ws2812_startup_sequence(void)
{
    if (!s_strip) return;
    const TickType_t delay = pdMS_TO_TICKS(20);

    // Fast lap: red -> green -> blue gradient chase.
    for (int i = 0; i < CONFIG_WS2812_LED_COUNT; ++i) {
        ws2812_clear();
        uint8_t r = (uint8_t)(255 - (i * 255 / (CONFIG_WS2812_LED_COUNT ? CONFIG_WS2812_LED_COUNT : 1)));
        uint8_t g = (uint8_t)(i * 255 / (CONFIG_WS2812_LED_COUNT ? CONFIG_WS2812_LED_COUNT : 1));
        uint8_t b = (uint8_t)(i * 255 / (CONFIG_WS2812_LED_COUNT ? CONFIG_WS2812_LED_COUNT : 1));
        led_strip_set_pixel(s_strip, i, ws2812_scale(r), ws2812_scale(g), ws2812_scale(b));
        (void)led_strip_refresh(s_strip);
        vTaskDelay(delay);
    }

    // Loading bar: fill to idle color one LED at a time.
    ws2812_clear();
    for (int i = 0; i < CONFIG_WS2812_LED_COUNT; ++i) {
        led_strip_set_pixel(s_strip, i, ws2812_scale(0), ws2812_scale(0), ws2812_scale(255));
        (void)led_strip_refresh(s_strip);
        vTaskDelay(delay);
    }
}

void gpio_init_all(void)
{
    ESP_LOGI(TAG, "Configuring GPIOs (simple)…");

    gpio_config_t io = {0};

    // -------- Inputs (all active-LOW; no internal pulls used) --------
    uint64_t input_mask = 0
        | BIT64(CONFIG_ENCODER_A_GPIO)
        | BIT64(CONFIG_ENCODER_B_GPIO)
        | BIT64(CONFIG_ENCODER_SW_GPIO)
        | BIT64(CONFIG_POS_SWITCH_GPIO)
        | BIT64(CONFIG_BUTTON_1_GPIO)
        | BIT64(CONFIG_BUTTON_2_GPIO);

    io.pin_bit_mask   = input_mask;
    io.mode           = GPIO_MODE_INPUT;
    io.pull_up_en     = GPIO_PULLUP_DISABLE;
    io.pull_down_en   = GPIO_PULLDOWN_DISABLE;
    io.intr_type      = GPIO_INTR_DISABLE;
    gpio_config(&io);

    // -------- Outputs (all push-pull; set LOW after config) --------
    uint64_t output_mask = 0
        | BIT64(CONFIG_BUZZER_GPIO)
        | BIT64(CONFIG_LED1_GPIO)
        | BIT64(CONFIG_LED2_GPIO)
        | BIT64(CONFIG_MOS_VALVE_GPIO)
        | BIT64(CONFIG_MOS_RESERVE_GPIO)
        | BIT64(CONFIG_OPEN_DRAIN_RESERVE_GPIO) // NOTE: currently push-pull
        | BIT64(CONFIG_RELAY_MOTOR_GPIO)
        | BIT64(CONFIG_RELAY_230V_GPIO)         // GPIO2 kept LOW at boot
        //| BIT64(CONFIG_SERVO_PWM_GPIO)          // LEDC will re-own later
        | BIT64(CONFIG_SERVO_ENABLE_GPIO);

    io.pin_bit_mask   = output_mask;
    io.mode           = GPIO_MODE_OUTPUT;
    io.pull_up_en     = GPIO_PULLUP_DISABLE;
    io.pull_down_en   = GPIO_PULLDOWN_DISABLE;
    io.intr_type      = GPIO_INTR_DISABLE;
    gpio_config(&io);

    // Safe defaults (everything OFF)
    gpio_set_level(CONFIG_BUZZER_GPIO, 0);
    gpio_set_level(CONFIG_LED1_GPIO, 0);
    gpio_set_level(CONFIG_LED2_GPIO, 0);
    gpio_set_level(CONFIG_MOS_VALVE_GPIO, 0);
    gpio_set_level(CONFIG_MOS_RESERVE_GPIO, 0);
    gpio_set_level(CONFIG_OPEN_DRAIN_RESERVE_GPIO, 0);
    gpio_set_level(CONFIG_RELAY_MOTOR_GPIO, 0);
    gpio_set_level(CONFIG_RELAY_230V_GPIO, 0);  // keep LOW for strap safety
    //gpio_set_level(CONFIG_SERVO_PWM_GPIO, 0);   // will be LEDC later
    gpio_set_level(CONFIG_SERVO_ENABLE_GPIO, 0);

    ESP_LOGI(TAG, "GPIOs configured.");
}




// Task: log each HX711 scale readout.
static void task_scale_log_readouts(void *arg)
{
    QueueHandle_t queue_hx711_readouts = (QueueHandle_t)arg;
    scale_sample_t s;

    while(1){
        if (xQueueReceive(queue_hx711_readouts, &s, portMAX_DELAY) == pdPASS) {
            ESP_LOGI("scale_consumer", "received new measurement: t=%lld ms  raw=%" PRId32 "  %.2f g %s",
                     (long long)s.ts_us/1000, s.raw, s.grams, s.valid ? "" : "(not-calibrated!)");
        }
    }
}



// Task: log encoder events and button state.
static void task_enc_consumer(void *arg)
{
    static const char *TAG = "encoder_consumer";
    QueueHandle_t q = (QueueHandle_t)arg;
    rotary_encoder_event_t ev;

    int32_t position = 0; // simple local pos accumulator

    for (;;) {
        if (xQueueReceive(q, &ev, portMAX_DELAY) != pdPASS) continue;
        switch (ev.type) {
        case RE_ET_CHANGED:
            position += ev.diff; // diff is +-1 per step (or more if accelerated)
            ESP_LOGI(TAG, "STEP %+d  pos=%ld", (int)ev.diff, (long)position);
            break;
        case RE_ET_BTN_PRESSED:
            ESP_LOGI(TAG, "BTN: pressed");
            break;
        case RE_ET_BTN_LONG_PRESSED:
            ESP_LOGI(TAG, "BTN: long pressed");
            break;
        case RE_ET_BTN_RELEASED:
            ESP_LOGI(TAG, "BTN: released");
            break;
        case RE_ET_BTN_CLICKED:
            ESP_LOGI(TAG, "BTN: clicked");
            break;
        default:
            break;
        }
    }
}



// Task: show encoder and scale values on the display.
#define LINE2PIXEL(n) ((n)*8)
#define DISPLAY_UPDATE_INTERVAL_MS 200

typedef struct {
    ssd1306_handle_t disp;
    QueueHandle_t    q_scale;  // scale_sample_t
    QueueHandle_t    q_enc;    // rotary_encoder_event_t
} disp_args_t;

static void task_display(void *arg)
{
    disp_args_t cfg = *(disp_args_t*)arg;
    vPortFree(arg);

    // simple local state
    float   grams = 0.f;
    bool    valid = false;
    int32_t enc_pos = 0;
    int8_t  enc_delta = 0;   // per-frame delta
    uint8_t btn = 0xFF;      // 0xFF = n/a, 0=UP, 1=DOWN
    uint8_t lastLine = 0;

    const TickType_t period = pdMS_TO_TICKS(DISPLAY_UPDATE_INTERVAL_MS);
    TickType_t last = xTaskGetTickCount();

    while(1) {
        //--- drain queues (show freshest data each frame) ---
        // get last scale readout from queue (if used)
        scale_sample_t smp;
        while (cfg.q_scale && xQueueReceive(cfg.q_scale, &smp, 1) == pdPASS) {
            grams = smp.grams;
            valid = smp.valid;
        }

        // also read the latest snapshot (fast-path, no queue)
        scale_latest_t latest;
        scale_latest_get(&latest);
        if (latest.ts_us != 0) {
            grams = latest.grams;
            valid = latest.valid;
        }

        // get last encoder event
        rotary_encoder_event_t ev;
        enc_delta = 0;
        while (cfg.q_enc && xQueueReceive(cfg.q_enc, &ev, 1) == pdPASS) {
            switch (ev.type) {
                case RE_ET_CHANGED:        enc_pos += ev.diff; enc_delta += (int8_t)ev.diff; break;
                case RE_ET_BTN_PRESSED:    btn = 1; break;
                case RE_ET_BTN_RELEASED:   btn = 0; break;
                case RE_ET_BTN_LONG_PRESSED: btn = 1; break;
                default: break;
            }
        }

        //--- draw display content ---
        lastLine = 0;
        char line1[24], line2[32];
        // clear framebuffer:
        ssd1306_clear(cfg.disp);

        // title:
        ssd1306_draw_text_scaled(cfg.disp, 0, LINE2PIXEL(lastLine), "Honey Filler", true, 2);
        lastLine += 2;
        // weight:
        if (valid) snprintf(line1, sizeof(line1), "%.1f g", grams);
        else       snprintf(line1, sizeof(line1), "--.- g");
        ssd1306_draw_text_scaled(cfg.disp, 0, LINE2PIXEL(lastLine), line1, true, 3); // big
        lastLine += 3;
        // encoder data:
        snprintf(line2, sizeof(line2), "Enc:%ld (%+d)  Btn:%s",
                 (long)enc_pos, enc_delta,
                 (btn==0xFF) ? "-" : (btn ? "DOWN" : "UP"));
        ssd1306_draw_text(cfg.disp, 0, LINE2PIXEL(lastLine), line2, true);
        lastLine += 2;

        // flush framebuffer, update display
        ssd1306_display(cfg.disp);

        vTaskDelayUntil(&last, period);
    }
}




// Task: simple servo sweep test.
static void task_servoTest(void *arg)
{
    while(1){
        // 100% = open, 0% = closed (works with inverted mechanics).
        ESP_ERROR_CHECK(gate_set_percent(100.0f));
        vTaskDelay(pdMS_TO_TICKS(2000));
        ESP_ERROR_CHECK(gate_set_percent(0.0f));
        vTaskDelay(pdMS_TO_TICKS(2000));
    }
    //read back the last set angle (calculated)
}





// Task: raw servo calibration using encoder + OLED (no gate clamp).
typedef struct {
    ssd1306_handle_t disp;
    QueueHandle_t    q_enc;
} gate_calib_args_t;

static void task_gate_calibrate(void *arg)
{
    gate_calib_args_t cfg = *(gate_calib_args_t*)arg;
    vPortFree(arg);

    float angle = 90.0f;     // start in a safe mid position
    const float step = 1.0f; // degrees per encoder tick
    bool dirty = true;

    ESP_LOGI(TAG, "gate_cal: start angle=%.1f deg", (double)angle);
    (void)iot_servo_write_angle(LEDC_LOW_SPEED_MODE, /*channel=*/0, angle);

    TickType_t last = xTaskGetTickCount();
    const TickType_t period = pdMS_TO_TICKS(100);

    while (1) {
        rotary_encoder_event_t ev;
        if (xQueueReceive(cfg.q_enc, &ev, pdMS_TO_TICKS(20)) == pdPASS) {
            if (ev.type == RE_ET_CHANGED) {
                angle += (float)ev.diff * step;
                if (angle < 0.0f) angle = 0.0f;
                if (angle > 180.0f) angle = 180.0f;
                ESP_LOGI(TAG, "gate_cal: angle=%.1f deg", (double)angle);
                (void)iot_servo_write_angle(LEDC_LOW_SPEED_MODE, /*channel=*/0, angle);
                dirty = true;
            }
        }

        if (dirty && (xTaskGetTickCount() - last) >= period) {
            last = xTaskGetTickCount();
            dirty = false;

            char line1[24];
            ssd1306_clear(cfg.disp);
            ssd1306_draw_text_scaled(cfg.disp, 0, LINE2PIXEL(0), "Gate Cal", true, 2);
            snprintf(line1, sizeof(line1), "Angle: %5.1f", (double)angle);
            ssd1306_draw_text_scaled(cfg.disp, 0, LINE2PIXEL(3), line1, true, 2);
            ssd1306_display(cfg.disp);
        }
    }
}
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
void app_main(void)
{

    //=======================
    //=== Queues (shared) ===
    //=======================
    // define queues used across multiple tasks
    QueueHandle_t queue_hx711_readouts = NULL;   // created by scale_hx711_start_poll(...)
    static QueueHandle_t queue_encoder_events = NULL;     // created here, used by encoder & UI
    queue_encoder_events = xQueueCreate(16, sizeof(rotary_encoder_event_t));
    assert(queue_encoder_events);


    //==================
    //==== init nvs ====
    //==================
    esp_err_t r = nvs_flash_init();
    if (r == ESP_ERR_NVS_NO_FREE_PAGES || r == ESP_ERR_NVS_NEW_VERSION_FOUND) {
        ESP_ERROR_CHECK(nvs_flash_erase());
        ESP_ERROR_CHECK(nvs_flash_init());
    }
    // Default to warnings; bump specific components as needed.
    // Strategy tags are raised explicitly so live dosing decisions and adaptive
    // learning logs remain visible during tuning runs.
    esp_log_level_set("*", ESP_LOG_WARN);
    esp_log_level_set("main", ESP_LOG_INFO);
    esp_log_level_set("app_params", ESP_LOG_INFO);
    esp_log_level_set("scale_hx711", ESP_LOG_WARN);
    esp_log_level_set("ui_task", ESP_LOG_INFO);
    esp_log_level_set("ui_menu", ESP_LOG_INFO);
    esp_log_level_set("gate", ESP_LOG_WARN);
    esp_log_level_set("buzzer", ESP_LOG_WARN);
    esp_log_level_set("io_test", ESP_LOG_WARN);
    esp_log_level_set("encoder_consumer", ESP_LOG_WARN);
    esp_log_level_set("scale_consumer", ESP_LOG_WARN);
    esp_log_level_set("filler_fsm", ESP_LOG_DEBUG);
    esp_log_level_set("fill_strategy", ESP_LOG_DEBUG);
    esp_log_level_set("fill_adaptive", ESP_LOG_DEBUG);
    esp_log_level_set("fill_flowctrl", ESP_LOG_DEBUG);
    esp_log_level_set("fill_manual", ESP_LOG_DEBUG);
    esp_log_level_set("telemetry", ESP_LOG_INFO);

    // Load persistent app parameters (targets/timeouts).
    app_params_init();
    app_params_t app_params = {0};
    app_params_get(&app_params);

    // Low-priority transport task for machine-readable telemetry. First step:
    // start the backbone and publish a few lifecycle records only.
    ESP_ERROR_CHECK(telemetry_start_task(CONFIG_TASK_PRIO_TELEMETRY, CONFIG_TASK_CORE_TELEMETRY));
    (void)telemetry_publish_boot("firmware_start");
    (void)telemetry_publish_preset(app_presets_get_active_index(),
                                   app_presets_get_name(app_presets_get_active_index()));


    //=============================
    //=== init Digital IO gpios ===
    //=============================
    gpio_init_all();


    //=====================
    //=== Buzzer output ===
    //=====================
    buzzer_init(CONFIG_BUZZER_GPIO);
    if (CONFIG_DISABLE_BUZZER) {
        ESP_LOGW(TAG, "Note: buzzer disabled by config");
        buzzer_set_enabled(false);
    }


    //=====================
    //=== WS2812 Strip ====
    //=====================
    #if CONFIG_WS2812_ENABLE
        led_strip_config_t strip_cfg = {
            .strip_gpio_num = CONFIG_WS2812_GPIO,
            .max_leds = CONFIG_WS2812_LED_COUNT,
            .led_model = LED_MODEL_WS2812,
            .color_component_format = LED_STRIP_COLOR_COMPONENT_FMT_GRB,
            .flags.invert_out = false,
        };
        led_strip_rmt_config_t rmt_cfg = {
            .clk_src = RMT_CLK_SRC_DEFAULT,
            .resolution_hz = 10 * 1000 * 1000,
            .flags.with_dma = false,
        };
        if (led_strip_new_rmt_device(&strip_cfg, &rmt_cfg, &s_strip) != ESP_OK) {
            ESP_LOGW(TAG, "WS2812 init failed");
        } else {
            ws2812_clear();
        }
    #else
        ESP_LOGW(TAG, "WS2812 disabled by config");
    #endif


    //===================
    //=== Motor relay ===
    //===================
    motor_init(CONFIG_RELAY_MOTOR_GPIO);


    //===================
    //=== HX711 scale ===
    //===================
    // Keep the default startup strict on the real machine, but allow an
    // explicit fake-sample mode for off-hardware telemetry testing.
    static scale_hx711_t scale;
    esp_err_t scale_err = ESP_OK;
    bool scale_fake_mode = (CONFIG_SCALE_FAKE_READS != 0);

    if (scale_fake_mode) {
        ESP_LOGW(TAG, "startup: using simulated scale samples");
    } else {
        scale_err = scale_hx711_init(&scale);
        if (scale_err == ESP_OK) {
            scale_hx711_set_default(&scale);
        } else if (CONFIG_SCALE_REQUIRED) {
            ESP_LOGE(TAG, "startup: scale init failed and the scale is required");
            ESP_ERROR_CHECK(scale_err);
        } else {
            ESP_LOGW(TAG, "startup: scale init failed; continuing without real scale");
        }
    }

    #define SCALE_RUN_CALIBRATION 0
#if SCALE_RUN_CALIBRATION //TODO: trigger this with UI
    // 1. zero readout (determine offset)
    printf("calibration: tare in 2 seconds... -> remove weight from scale\n");
    vTaskDelay(pdMS_TO_TICKS(2000));
    ESP_ERROR_CHECK(scale_hx711_tare(&scale, 16));
    // 2. calibrate (determine scale)
    printf("calibrating to 500g in 2 seconds... -> pace weight\n");
    vTaskDelay(pdMS_TO_TICKS(2000));
    ESP_ERROR_CHECK(scale_hx711_calibrate(&scale, 500.0f, 16));
#endif


    //======================
    //=== Rotary Encoder ===
    //======================
    ESP_LOGI(TAG, "startup: initializing rotary encoder");
    // Init the encoder library with that queue
    ESP_ERROR_CHECK(rotary_encoder_init(queue_encoder_events));

    // Describe encoder pins (button optional)
    static rotary_encoder_t enc = {
        .pin_a  = CONFIG_ENCODER_A_GPIO,      // e.g. GPIO36
        .pin_b  = CONFIG_ENCODER_B_GPIO,      // e.g. GPIO39
        .pin_btn= CONFIG_ENCODER_SW_GPIO,     // e.g. GPIO34, or >=GPIO_NUM_MAX if none
    };
    // Register encoder
    ESP_ERROR_CHECK(rotary_encoder_add(&enc));
    ESP_LOGI(TAG, "startup: rotary encoder ready");
    // (Optional) Acceleration for faster turning feel
    //ESP_ERROR_CHECK(rotary_encoder_enable_acceleration(&enc, 400));


    //===============
    //=== Display ===
    //===============
    ssd1306_handle_t disp = startup_init_display();


    //=======================
    //==== Gate (Servo) =====
    //=======================
    gate_cfg_t gate_cfg = {
        .mode = LEDC_LOW_SPEED_MODE,
        .timer = LEDC_TIMER_0,
        .ch = LEDC_CHANNEL_0,
        .pwm_gpio = CONFIG_SERVO_PWM_GPIO,
        .en_gpio = CONFIG_SERVO_ENABLE_GPIO,
        // If mechanics are inverted, set open_deg < close_deg.
        .open_deg = app_params.gate_open_deg,
        .close_deg = app_params.gate_close_deg,
    };
    ESP_LOGI(TAG, "startup: initializing gate servo");
    ESP_ERROR_CHECK(gate_init(&gate_cfg));
    ESP_LOGI(TAG, "startup: gate servo ready");
    if (CONFIG_DISABLE_SERVO) {
        ESP_LOGW(TAG, "Note: gate disabled by config");
        gate_set_enabled(false);
    }






    //=======================
    //=== Start all tasks ===
    //=======================
    //--- buzzer task ---
    ESP_LOGI(TAG, "startup: starting buzzer task");
    buzzer_task_start(3);


    // --- STARTUP SEQUENCE ---
    ESP_LOGI(TAG, "startup: running startup sequence");
    buzzer_beep_short(3);
    if (CONFIG_WS2812_ENABLE && s_strip) {
        ws2812_startup_sequence();
    }
    ESP_LOGI(TAG, "startup: startup sequence complete");


    //--- weight scale task ---
    if (scale_fake_mode) {
        ESP_LOGI(TAG, "startup: starting simulated scale task");
        ESP_ERROR_CHECK(scale_hx711_start_fake_poll(
            pdMS_TO_TICKS(CONFIG_HX711_POLL_INTERVAL_MS),
            1,
            &queue_hx711_readouts));
    } else if (scale_err == ESP_OK) {
        // Start producer - constantly reads HX711 and updates a queue.
        ESP_LOGI(TAG, "startup: starting HX711 scale task");
        ESP_ERROR_CHECK(scale_hx711_start_poll(
            &scale,
            CONFIG_HX711_AVG_SAMPLE_COUNT,
            pdMS_TO_TICKS(CONFIG_HX711_POLL_INTERVAL_MS),
            1,
            &queue_hx711_readouts));
    } else {
        ESP_LOGW(TAG, "startup: no scale source active; skipping scale task");
    }
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

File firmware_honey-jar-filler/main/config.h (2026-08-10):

#pragma once
#include "driver/gpio.h"

// Assign GPIO pins and configure options in this file


//===========================
//===== Input GPIO pins =====
//===========================
// all inputs are active LOW (switches wired to pull input to GND)
#define CONFIG_ENCODER_A_GPIO     GPIO_NUM_39  // board pullup desoldered for encoder module to work
#define CONFIG_ENCODER_B_GPIO     GPIO_NUM_36  // board pullup desoldered for encoder module to work
#define CONFIG_ENCODER_SW_GPIO    GPIO_NUM_34

#define CONFIG_POS_SWITCH_GPIO    GPIO_NUM_35
#define CONFIG_BUTTON_1_GPIO      GPIO_NUM_32
#define CONFIG_BUTTON_2_GPIO      GPIO_NUM_33



//============================
//===== Output GPIO pins =====
//============================
// all outputs are active high (device turns on when output high)
#define CONFIG_BUZZER_GPIO          GPIO_NUM_17
#define CONFIG_LED1_GPIO            GPIO_NUM_26
#define CONFIG_LED2_GPIO            GPIO_NUM_25

#define CONFIG_MOS_VALVE_GPIO       GPIO_NUM_5
#define CONFIG_MOS_RESERVE_GPIO     GPIO_NUM_18
#define CONFIG_OPEN_DRAIN_RESERVE_GPIO GPIO_NUM_14

#define CONFIG_RELAY_MOTOR_GPIO     GPIO_NUM_27
#define CONFIG_RELAY_230V_GPIO      GPIO_NUM_2


//============================
//===== Optional disables ====
//============================
// 1 = disable output, 0 = normal operation.
#define CONFIG_DISABLE_BUZZER      0


//============================
//======= WS2812 LED =========
//============================
// Single-wire addressable LED strip (WS2812B).
#define CONFIG_WS2812_ENABLE        1
#define CONFIG_WS2812_GPIO          GPIO_NUM_23
#define CONFIG_WS2812_LED_COUNT     50
#define CONFIG_WS2812_MAX_BRIGHTNESS_PCT 15


 
//=======================================
//==== HX711 24 bit ADC (load-cell) =====
//=======================================
#define CONFIG_HX711_DT_GPIO        GPIO_NUM_19 // re-routed using jumper wire on the back
//#define CONFIG_HX711_DT_GPIO        GPIO_NUM_12 //according to pcb layout, but causes crash on nvs write (strapping pin)
#define CONFIG_HX711_SCK_GPIO       GPIO_NUM_13

// sample interval / averaging - consider one readout takes ~90ms
#define CONFIG_HX711_POLL_INTERVAL_MS 100 //note: INTERVAL > COUNT * 90ms
#define CONFIG_HX711_AVG_SAMPLE_COUNT 1  //note: COUNT < INTERVAL / 90ms

// Startup policy for development:
// - REQUIRED keeps the real machine strict and fails startup on missing scale HW.
// - FAKE_READS bypasses the HX711 and publishes simulated samples instead.
#define CONFIG_SCALE_REQUIRED       1
#define CONFIG_SCALE_FAKE_READS     0



//===============================
//====== I2C OLED Display =======
//===============================
#define CONFIG_DISPLAY_SDA_GPIO     GPIO_NUM_21
#define CONFIG_DISPLAY_SCL_GPIO     GPIO_NUM_22
// If the display is optional, startup will continue headless when probing fails.
#define CONFIG_DISPLAY_REQUIRED     0
#define CONFIG_DISPLAY_PROBE_TIMEOUT_MS 50



//=======================
//======== Servo ========
//=======================
#define CONFIG_DISABLE_SERVO       0
#define CONFIG_SERVO_PWM_GPIO       GPIO_NUM_4  // Servo PWM Signal: directly connected to terminal (no pulldown present)
#define CONFIG_SERVO_ENABLE_GPIO    GPIO_NUM_16  // P-MOSFET Enable supply for Servo (outputs 12V when HIGH)




//=======================================
//=========== Task priorities ===========
//=======================================
// Higher number = higher priority (ESP-IDF max is configMAX_PRIORITIES-1).
// Keep HX711 > FSM > UI for stable weight reads.
#define CONFIG_TASK_PRIO_HX711       8
#define CONFIG_TASK_PRIO_FSM         6
#define CONFIG_TASK_PRIO_UI          3

// Core pinning: 0=PRO CPU, 1=APP CPU, tskNO_AFFINITY lets FreeRTOS choose.
#define CONFIG_TASK_CORE_HX711       0
#define CONFIG_TASK_CORE_FSM         1
#define CONFIG_TASK_CORE_UI          1

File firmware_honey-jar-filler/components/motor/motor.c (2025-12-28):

#include "motor.h"

// Local storage for the relay GPIO.
static gpio_num_t s_relay_gpio = GPIO_NUM_NC;

void motor_init(gpio_num_t relay_gpio)
{
    s_relay_gpio = relay_gpio;

    // Configure relay GPIO as push-pull output.
    gpio_config_t io = {
        .pin_bit_mask = (1ULL << relay_gpio),
        .mode = GPIO_MODE_OUTPUT,
        .pull_up_en = GPIO_PULLUP_DISABLE,
        .pull_down_en = GPIO_PULLDOWN_DISABLE,
        .intr_type = GPIO_INTR_DISABLE,
    };
    gpio_config(&io);

    // Default safe state: brake (relay OFF).
    gpio_set_level(s_relay_gpio, 0);
}

void motor_set(bool on)
{
    if (s_relay_gpio == GPIO_NUM_NC) return;
    gpio_set_level(s_relay_gpio, on ? 1 : 0);
}

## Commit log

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2025-10-29 Add kicad project - base components designed (schematic)
    [Digital-Input-Filter.kicad_sch, pcb_honey-jar-filler.kicad_pcb, pcb_honey-jar-filler.kicad_sch]
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2025-11-08 pcb: Fix invalid text
    [pcb_honey-jar-filler.kicad_pcb]
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2025-11-08 pcb: Arrange fab text, Annotate for soldering, Fix "PWM" text
    [pcb_honey-jar-filler.kicad_pcb, pcb_honey-jar-filler.kicad_sch]
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2025-12-21 CAD: Adjust index (switch to magnets), Add slide-plate screws + reed mount
    [carousel.FCStd, servo-mount.FCStd]
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2025-12-27 CAD - base: apply fixes, add led-strip, loadCell-guard, cable guide
    [base.FCStd]
2025-12-27 CAD - servo-mount: fix encoder, add lever-v2
    [servo-mount.FCStd]
2025-12-28 FW: Add servo-calibration-task, toggle-gate-task, Rework gate component (percentage + logging)
    [gate.c, main.c]
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2025-12-28 FW: Add custom components fsm, ui - WIP crashes on calibration nvs store
    [filler_fsm.c, main.c, ui_task.c]
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2025-12-29 Fix crash on nvs-write: Change H711 DT-pin (non strapping), Add notes to schematic + pcb
    [pcb_honey-jar-filler.kicad_pcb, pcb_honey-jar-filler.kicad_sch]
2025-12-29 FW: Add custom component buzzer, beep at encoder, beep on state change
    [buzzer.c, filler_fsm.c, main.c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]
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2025-12-30 FW: Add silent mode, led startup sequence, by-state led colors, Fix rotating too far
    [buzzer.c, config.h, filler_fsm.c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]
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2025-12-30 FW: Fix 'hx711_read_average failed' using other core and task priority
    [config.h, main.c, scale_hx711.c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]
2025-12-30 FW: Ignore measurement spikes (sable for n), Fix servo oscillation / gate threshold not loosened at retry
    [buzzer.c, filler_fsm.c]
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2026-01-02 FW: Adjust app params, Fix dup code - generate struct typdef from param def
    [filler_fsm.c, ui_task.c]
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2026-06-01 FW: Fix scale readout invalid (calibrated flag was not set)
    [scale_hx711.c]
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2026-06-11 TOOL: Fix telemetry uart line interleaving, Add capture status-line
    [capture.py]
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2026-06-15 FW: Fixes in adaptive strategy during actual test (min refill, longer timeout...)
    [capture.py]
2026-06-17 TOOL: Optimize chart plot, Fix splitting
    [analysis.py, plot_runs.py, split_runs.py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]
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2026-06-18 TOOL: Fix broken layout in chart tool, Add summary-plots per session
    [plot_runs.py, telemetry_tui.py]
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2026-07-04 FW: Adaptive strategy - faster/stable learning, grounded near-close, stronger failsafes
    Learning:
    - Warmup EWMA (a=max(base, 1/(n+1))): the first successful fill fully adopts
    its measurement instead of blending with the conservative preset seed, so
    dead-time/post-close/rate/drip-wait converge in a couple of jars.
    - Replace the self-referential near-close bias (measured the window it set, so
    it drifted ~+0.7 g/fill up to the clamp) with a grounded window: in-flight
    mass over the reduction dead time plus a slow-phase settle margin sized from
    the (previously unused) learned slow rate. First jar still honours the
    preset's slow_remaining_g until a slow rate is measured.
    - Fix ewma() b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
2026-07-04 FW: Relax over-strict sanity checks, Proportional refill, Conservative drip learn
    Sanity checks (adaptive):
    - No-response fault was too strict: 7 s floor / 12 s cap would cancel thick
    honey (large dead time, e.g. 10 s) - especially the first jar where the dead
    time is not learned yet. Raise to 15..30 s and DEAD_TIME_MAX to 15 s.
    - Safe-rate cutback now debounces over consecutive samples, so the brief flow
    spike when honey first hits the glass no longer reduces the gate or faults.
    Refill (both heuristic modes):
    - Relax the close threshold by ~the measured deficit (0.9x, floored at the old
    step) instead of a fixed small step, so a single refill reaches the target
    band instead of man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
2026-07-04 FW: Flow-control - port adaptive learning/safety optimizations
    Bring the flow-control (rate-regulated gate) strategy in line with the adaptive
    strategy improvements:
    - Warmup EWMA (learn_ewma): first successful fill fully adopts its measurement
    so the fallback rate/dead-time seeds are dropped in a couple of jars (also
    gives the rate controller a realistic setpoint much sooner).
    - Fix signed EWMA bug on finish_trim (the prev<=0 shortcut replaced a
    zero/negative trim wholesale instead of filtering it).
    - Relax over-strict sanity checks: DEAD_TIME_MAX 3->15 s, no-response 1.2/6 ->
    15/30 s, so thick honey (long dead time) and the first jar are not cancelled.
    - Safe-rate: absolute jar-siz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
2026-07-04 FW: Add new fill strategy: flow-cascade (PI + deceleration profile + Smith predictor, untested)
    Regelungsbasierter Ansatz for the thesis: a cascade controller built on the
    adaptive/flow-control scaffolding (learning-with-warmup, safety failsafes,
    telemetry, FSM). New control law:
    - Inner PI rate loop with feedforward gate (= ṁ*/K̂), anti-windup, step limit,
    dead-time-paced updates (holdoff ~ learned dead time).
    - Outer continuous deceleration rate profile ṁ* = f(remaining), in-flight
    compensated (replaces the two fixed setpoints of flow-control).
    - Smith predictor for dead-time compensation: fb = ŷ + (ṁ_m − ŷ_d), with a
    ŷ_d = 0 cold-start so it does not wind up during the i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
    [scale_hx711.c]
2026-07-05 FW: Add new fill strategy: sequence (scripted timed gate script for a Strecke reference chart)
    A crude plant-probe strategy with no target/learning logic: it runs a fixed,
    hard-coded timed gate script (edit k_seq[], default 30% 5s -> 90% 5s -> close
    10s) and logs telemetry like the dosing strategies (weight, gate, raw/filtered
    rate), then reports success so the carousel advances. Purpose: capture a clean,
    repeatable Strecke response (dead time, rate build-up per gate step, post-close
    drip) to discuss in the thesis. Registered as APP_FILL_STRATEGY_SEQUENCE
    ("sequence").
2026-07-05 FW: Add temporary slow-learning toggle to adaptive strategy for thesis charts
    Compile-time ADAPT_LEARN_SLOW (default 0 = optimized). Set to 1 to disable the
    first-fill warmup and scale learning alphas down (x0.35) so the adaptive
    parameters ease gradually from the conservative preset defaults over several
    fills - making the convergence trend (shorter, more accurate fills run by run)
    clearly visible in the learning charts. Temporary thesis aid; reflash to switch.
2026-07-05 TOOL: Fix live-capture log scrolling on short terminals
    The sticky status footer (3 status lines + 8-row weight chart) had a fixed
    height and was sized only from the terminal width; the terminal height was
    never checked. On a short terminal the 11-line footer left no room for the log
    scroll region, so console output looked static (only worked on taller windows).
    Size the footer to the terminal height via compute_status_geometry(): shrink
    the weight chart (down to 0 on tiny terminals) so at least MIN_LOG_ROWS rows
    always remain for scrolling logs. Recomputed each refresh, so it also adapts to
    live window resizes. Tall terminals are unchanged (full-height chart).
    [capture.py]
2026-07-05 TOOL: Add Syncthing .stignore to stop the git database from being synced
    Syncthing copied .git file-by-file, racing/partially-updating git's object
    store and index. This corrupted the repo (a commit captured a stale reverted
    tree; the laptop hit "packfile ... index unavailable"). Exclude /.git (and
    build/history/cache artifacts) so the working tree can still sync while code
    history is synced properly via git push/pull. Note: .stignore is per-device and
    not auto-synced - it must also be created on other machines.
2026-07-05 FW: Pin esp-idf-lib/encoder to ^1.1.0, commit dependencies.lock, doc build repro
    esp-idf-lib/encoder shipped a breaking API rewrite in v2.0.0 (rotary_encoder_init/
    add -> rotary_encoder_create); the unbounded '*' range in idf_component.yml plus a
    gitignored dependencies.lock let a fresh clone silently resolve to the incompatible
    latest version and fail to compile. Pin the version, track the lock file, and stop
    ignoring it so builds are reproducible across machines.
2026-07-05 FW: Add restart-controller menu action to reset in-session learning
    New home-menu item "Restart controller" (after Calibrate scale) that beeps and
    calls esp_restart(). Learned values in the adaptive / flow-control / flow-cascade
    strategies live only in RAM for the boot session, so a reboot clears them and
    the next jar starts from the preset defaults again - a clean, intentional
    learning reset between chart runs without power-cycling the hardware.
2026-07-05 TOOL: Fix live-capture log freeze by using a real ANSI scroll region
    The previous fix (91fc296) sized the footer to the terminal height but still
    positioned the sticky footer and log lines with relative cursor motions
    (\x1b[1B / \x1b[NA), assuming ordinary newline printing would scroll the
    whole screen once the footer reached the bottom. Relative motions clamp
    instead of scrolling once the cursor hits the last row, so the anchor point
    silently drifted down by one row per console line without the terminal ever
    scrolling to compensate -- eventually the footer redraw landed past the
    bottom of the screen and clobbered the just-printed log line, making the log
    look frozen exactly once the chart r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
    [capture.py]
2026-07-05 FW: Tune safe-rate limiting across cascade/flow-control/adaptive strategies
    Loosen the abs safe-rate ceiling (target_g / MIN_CONTROLLED_FILL_S 8.0->4.0s
    in all three strategies) so small jars can run their intended high g/s
    operating point without the limiter constantly fighting the controller; a
    200g jar was previously hard-floored at 25 g/s regardless of what was
    learned.
    In cascade and flow-control (continuous gate control), replace the flat
    safe-rate gate cut (a fixed -6% applied on every single sample once
    triggered) with a progressive, dead-time-paced reduction: step size now
    scales with how far over the limit the rate is (small overshoot -> small
    nudge, real runaway -> large fast ste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
2026-07-05 FW: Learn from overweight misses in cascade, slow the demo flow rate
    Learning was gated on success alone, so an overweight verify failure -- a
    normal close+drip-wait cycle that just landed high -- fed back nothing,
    letting the same underestimated post_close_gain repeat the miss next fill.
    Overweight now counts as learnable data (other fault reasons still don't:
    they abort mid-fill or come from stale data), and finish_trim gets a much
    larger corrective alpha on a miss than the steady-state fine-tuning nudge, so
    the very next fill actually adjusts. successful_fills still only increments
    on true success, so repeated misses keep getting the fast warmup alpha.
    Also lower the un-learned fast/slow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
2026-07-06 TOOL: Extend chart script with new cascade-control data/subplot, Fix margin
    [plot_runs.py, telemetry_tui.py]
2026-07-10 FW: Rework flow-cascade plant model to affine rate=K*gate+b, Fix overfill and flat profile
    Replace the 6-point gate->rate breakpoint schedule with a single affine model
    rate = K*gate + b, fit live from two EWMA operating points (fast phase = high
    gate, slow phase = low gate) once the gate is steady past dead time. The
    breakpoints never got data (controller only visits two gate regimes) so the
    "effective gain" drifted; the offset b captures the non-zero flow onset (~15%
    gate) that made a pure scalar gain unstable. Feedforward is now gate=(m*-b)/K;
    K and b persist per preset via signed-safe learn_ewma.
    Fix overfill (+15..23 g every fill): drop the predicted_remaining double-count
    (post_close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
2026-07-10 DOC: Update CLAUDE.md handoff with cascade affine model, pitfalls, current state
    Fold this session's learnings into the auto-loaded context doc so new sessions
    start informed: flow-cascade now uses an affine plant model rate=K*gate+b (why
    the scalar/breakpoint approaches failed, two-point live fit, first-fill b=0
    caveat); new CASC_GAIN_* constants; RAM-only learned state; and a "Pitfalls
    already hit" section (Syncthing must not sync .git, ewma prev<=0 corrupts signed
    values, no gate-sweep schedules, first-fill warmup dominance). Point cascade
    retest at doc/cascade-affine-gain-testnotes.md and note the uncommitted
    plot_runs control-panel wiring.
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2026-07-15 FW: Cascade drip oscillation - long control window, learned flow-onset, min-flow floor
    Run 2026.07.15_22:39 confirmed the drip-robust K identification works: K settles
    ~0.44-0.62 with b<0 (was pinned at the 0.10 floor), and every jar lands 142-148 g
    on a 150 g target. But the loop still oscillates flow<->no-flow, and the telemetry
    shows why: of 175 samples in one fill, 52 read ~zero flow but only 16 are below
    onset -- the no-flow is mostly the sticky medium releasing in ~1 s bursts even at
    a steady 21-28% gate, and the 0.5 s control window let the loop chase each burst.
    - Control feedback now a least-squares slope over ~1.5 s (drip period) instead of
    0.5 s, so the loop sees the smooth mea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
    [cascade_analyze.py]
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2026-07-16 FW: Cascade gain-ID - harvest one observation per steady dwell, relax min window
    The gain identification only fired when the gate sat still for dead_time + 1.5 s.
    Measured on the 2026-07-15 test4 run that was met 0-1 times per FILL (fills 2-5:
    zero), so K was effectively never updated from real data. Worse, which dwells
    qualified was selection-biased: the gate only holds still while the loop is
    quiet, i.e. while little is flowing, so the only observations that ever landed
    were the low-gate/low-flow ones (21%/3.4, 24%/6.7, 28%/10.1 g/s) while the
    informative high-flow dwell (33%/24 g/s, held 1.0 s) was rejected. K was fitted
    from the flattest part of the curve and came out ~2.7x too small (0.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
2026-07-16 FW: Cascade plant ID by RLS, Drop the seed-anchored two-point fit, Relax K floor
    The two-point fit was structurally incapable of identifying the plant. The high
    operating point was seeded at 60 % gate, the controller only ever visits ~12-37 %,
    and the bin boundary was the midpoint of the two points (=45 %) -- so EVERY
    observation fell in the low bin and the high point never left its seed (measured:
    gain_hi_gate_pct = 60.0 in all 7 fills of the test4 run, with gain_hi_rate_gps
    just K_old*60+b_old re-derived from itself). At the fixed point the algebra
    collapses to K = rate_lo/(gate_lo - onset), with onset learned as gate - rate/K
    from that same point: two unknowns, one equation. The pair drif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
    [cascade_analyze.py, scale_hx711.c]
2026-07-16 DOC: Update CLAUDE.md for the cascade RLS/tau rework, Correct the wrong K claim
    The handoff doc described the two-point fit that no longer exists and asserted
    "K settles ~0.5, confirmed working" - which the telemetry contradicts: an offline
    fit over that same session gives K=1.42, so the firmware was 2.7x low. Left as-is
    it would have sent the next session chasing symptoms.
    Record what the analysis actually found: why the two-point fit was structurally
    unidentifiable (seeded high point outside the visited gate range + a self-locking
    bin boundary => two unknowns from one equation), that RLS replaces it, and that
    tau is load-bearing for the observation de-bias rather than cosmetic. Add the
    or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
2026-07-18 PCB: Optimize Schematic layout for thesis exports (Servo supply + Motor relay)
    [Digital-Input-Filter.kicad_sch, pcb_honey-jar-filler.kicad_sch]
2026-07-18 TOOL: cascade_analyze - reconstruct gain observations offline, add ground-truth fit + diagnosis
    The firmware's gain_obs_* logging is unreliable (a self-clearing one-sample
    impulse that the telemetry emit almost never catches -> n_obs read 0 on every
    fill despite the estimator running), so trusting it hid what the identifier was
    actually fed. Reconstruct the steady (gate, rate) observations OFFLINE from raw
    weight + gate using the same dwell definition the firmware uses, so the analysis
    no longer depends on that logging.
    Per fill, show the firmware's believed K/onset/tau beside an offline ground-truth
    affine fit over that fill's observations, and flag when the firmware K is on a
    rail or far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
    [cascade_analyze.py]
2026-07-18 FW: Replace cascade RLS with a single local gain (K=EWMA of rate/(gate-onset)), Fix obs logging
    The RLS identifier diverged on the 2026-07-18 run: K was pinned to a rail
    (<=0.03 or >=3.0) in ~half of all samples, which made the feedforward gate
    garbage and slammed it to 0/100 %. Root cause is structural, not a tuning bug:
    RLS fits ONE global affine line rate=K*gate+b, but the real plant is nonlinear
    (rate saturates at high gate) AND non-stationary (bucket head falls as it
    drains), so the session's gate->rate cloud is not even monotonic - an offline
    global fit gives K=-0.13. Fitting a line to that, with forgetting + state
    projection, is unstable. (Chain of failed models now closed: scalar-thr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
    [cascade_analyze.py, scale_hx711.c]
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2026-07-18 DOC: Update CLAUDE.md for the local-gain estimator, identification probe, cascade charts
    Bring the handoff doc in line with the RLS -> local-gain -> probe arc: correct
    the stale "identified by RLS" block, record why RLS diverged (global affine fit
    over a nonlinear + non-stationary plant), the local gain that replaced it, the
    starvation it exposed, and the identification probe that feeds it. Note the new
    plot_runs.py cascade session-summary group and repoint the retest checklist at
    commit 85dd164 (probe) with the topped-up-bucket caveat.
2026-07-18 FW: Cascade - probe becomes the opening step (feeds tau), lower tau seed, learning logs
    test3 (21:27) showed the probe working (19 observations vs 3), K learning, and the
    Smith model finally tracking the measured rate. Two follow-ups from that run:
    - tau still sat near its 0.60 s seed (learned only twice) and read too high for a
    medium that visibly shoots up almost instantly after the dead time. Lower the
    seed to 0.20 s, cap the max at 1.20 s (nothing here rises slower), and -- the
    reliability fix -- OPEN THE FILL DIRECTLY AT THE PROBE GATE when the probe is
    armed. The probe hold is then the fill's opening step: the rate rises from zero
    at a constant gate, which is exactly the cle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
2026-07-18 FW: Cascade - fix onset as a constant, calm the rate loop to stop the limit cycle
    Two changes from the 22:25 (test4) run, where K converges well (0.59->1.18) and
    tau is now realistic (~0.16) but the gate still oscillates badly.
    1. Onset is no longer "learned". It cannot be identified from a steady point:
    given K, onset = gate - rate/K just re-derives where the fitted line crosses
    zero, so it carries no independent information and only added a spurious DOF
    that drifted up to 19 % on the draining fills and dragged K with it. The dead
    angle is a threshold-crossing, measurable only by slowly ramping the gate and
    watching flow start/stop (a separate identification, left as future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
2026-07-19 TOOL: plot_runs - cascade thesis-chart polish (control_rate series, model styles, sparse gate labels, compact params)
    For the flow-cascade thesis figures:
    - Add a "control" rate series (control_rate_gps) -- the drip-averaged rate the
    loop actually regulates on and the model is identified against. It is the
    honest "measured rate" to compare against setpoint and prediction, far cleaner
    than the jumpy filtered rate.
    - Rate panel: draw the dead-time-delayed model output yhat_d SOLID (it should
    line up with the measured rate) and the delay-free yhat DOTTED (the reference
    showing how far ahead the prediction runs) -- swapped from before.
    - Gate labels: for flow-cascade (like flow-control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
    [plot_runs.py]
2026-07-19 TOOL: plot_runs - thesis chart polish (blue measured rate, plain session charts, compact panels)
    - Cascade timeseries: measured control rate is blue and labelled "Gefilterte
    Füllrate [g/s]" again, consistent with the other diagrams.
    - Session-cascade-params: move the L/tau legend to the upper right (was colliding
    with the lines); render K-hat via mathtext $\hat{K}$ (the combining-circumflex
    unicode was drawing the roof inside the K).
    - All Sitzungsübersicht variants: drop the top title + subtitle (plain/compact for
    the thesis; the caption carries the context).
    - Session-summary: refills panel at half height (it only toggles 0/1).
    - Adaptive parameter summary: drop the near-constant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
    [plot_runs.py]
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2026-08-10 DOC: README overhaul - system-overview CAD render, dosing-strategies section, fix ESP-IDF version (5.5.1), list analysis tools; gitignore editor .history; add firmware roadmap doc
2026-11-01 FW: Add new fill strategy: adaptive-gate (adaptive heuristic + learned gate openings)
    Adaptive heuristic FSM and safeguards, but the fast/reduced gate openings are
    learned per preset so each phase runs at a target rate instead of fixed preset
    percentages - compensates the draining bucket, refills and honey changes
    without tuning. Deliberately not a continuous controller:
    - Between fills: steady least-squares rate per phase moves the learned gate
    only outside a +-15 % band (reduced phase +-25 %, two agreeing fills),
    damped (alpha 0.75, step halving on reversal), drain lead on upward steps.
    - Within a fill only gross cases act: too fast (1.5x cumulative / 2x sliding
    window), too slow (<1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
2026-11-01 TOOL: Add host strategy simulator (real firmware strategy code vs closed-loop plant)
    - tools/sim/build.sh compiles the real components/filler strategy sources
    against ESP-IDF/FreeRTOS shims (file-backed NVS for reboot tests) into a
    shared library; harness.c reproduces the FSM's on_enter/step pattern.
    - plant.py: closed-loop plant from synth_plant_session.py physics plus bucket
    head, head-dependent dead time (L = l_min + m_build/q, fitted on adaptive-fix4)
    and media profiles calibrated on the recorded sessions (thin dummy, dark thin
    honey, fake honey, thick honey, concave-curve variant).
    - fillsim.py session runner (jar swaps, refill/medium/reboot/mid-fill events,
    optional NDJSON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
2026-11-01 FW: adaptive-gate - never stuck at a too small opening (cold start 50 %, keep opening on no flow, fix inverted in-fill direction lock), reduced gate follows in-fill corrections
    First hardware try (no honey, hand presses) sat at a too small opening:
    30 % start, only 2 no-flow bumps (+12 %), and a hand press counted as flow
    response after which only the limited too-slow rule could open further.
    - Cold start 50 % (thick honey flows at once, thin honey is caught by the
    safe-rate cutback / too-fast rule), no-flow bumps +15 % up to 100 %,
    no-response fault only 30-45 s after the last bump.
    - New "zero flow after a response" rule (fast and reduced phase): a steady
    rate of ~0 always opens furt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
2026-11-01 FW: adaptive-gate - operator-like stops (jar removed, bucket empty mid-fill), gross reversal of in-fill corrections, reduced-phase no-flow steps towards the fast gate, floor decay
    Adversarial sim pass found cases where the strategy did not act like a person:
    - Jar taken away mid-fill looked like "no flow": the zero-flow rule opened
    further and the whole bucket (3-6 kg) poured onto the carousel until the
    10 min timeout; during drip/verify it would "refill" a missing jar. Now: jar
    weight >25 g (or 5 % of target) below its maximum -> close + NO_JAR fault.
    - Bucket running dry mid-fill or in a refill waited for the 10 min timeout.
    Now: fully open and ~0 flow in the sliding window for the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
